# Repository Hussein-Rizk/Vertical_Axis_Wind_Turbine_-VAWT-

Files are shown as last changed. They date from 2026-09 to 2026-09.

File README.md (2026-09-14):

# 🌬️ Vertical Axis Wind Turbine (VAWT) — Graduation Project I

**Year:** 2024  
**Program:** Mechatronics Engineering  
**University:** Mansoura University  
**Main Tools:** QBlade, SolidWorks, AirfoilTools  
**Project Type:** Graduation Project I  

This project investigates the **design, aerodynamic analysis, simulation, and prototyping of a Vertical Axis Wind Turbine (VAWT)**.

The work combines a theoretical comparison between **Horizontal Axis Wind Turbines (HAWTs)** and **Vertical Axis Wind Turbines (VAWTs)** with airfoil selection, QBlade simulation studies, CAD design, manufacturing preparation, and construction of a physical VAWT prototype.

The final prototype was developed after comparing several NACA airfoils and evaluating turbine performance using **QBlade**.

---

## 📸 VAWT Prototype

<p align="center">
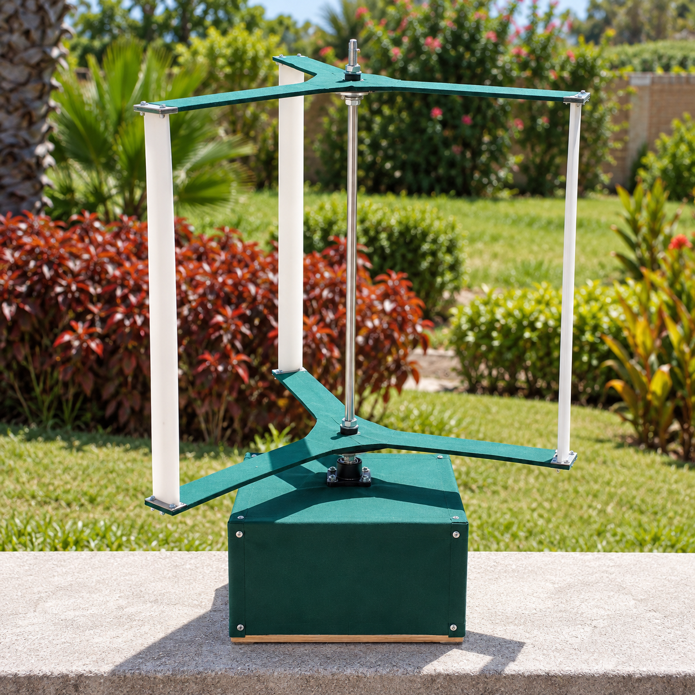
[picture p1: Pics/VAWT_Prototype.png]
  
</p>

The image above shows the fabricated **Vertical Axis Wind Turbine prototype** developed during the project.

---

## 🎯 Project Objectives

The project focuses on:

- studying the differences between **HAWT** and **VAWT** systems
- investigating aerodynamic parameters affecting wind-turbine performance
- comparing different **NACA airfoils**
- studying lift, drag, glide ratio, Reynolds number, tip-speed ratio, and power coefficient
- creating HAWT and VAWT case studies in **QBlade**
- selecting a suitable airfoil for the final VAWT prototype
- designing prototype components in **SolidWorks**
- preparing **DXF files** for manufacturing / laser cutting
- constructing and testing a physical VAWT prototype

---

## 🌀 HAWT Study

The HAWT case study compares four NACA airfoils:

- **NACA 1408**
- **NACA 2412**
- **NACA 6409**
- **NACA 6412**

For each airfoil, the project studies parameters such as:

- blade chord distribution
- twist angle
- Reynolds number
- tip-speed ratio
- lift coefficient
- angle of attack

The calculated blade geometry was then implemented and evaluated in **QBlade**.

### HAWT Study Files

```text
HAWT/
├── NACA 1408 HAWT V1.1.qpr
├── NACA 1408 HAWT V1.1.xlsx
├── NACA 2412 HAWT V1.1.qpr
├── NACA 2412 HAWT V1.1.xlsx
├── NACA 6409 HAWT V1.1.qpr
├── NACA 6409 HAWT V1.1.xlsx
├── NACA 6412 HAWT V1.1.qpr
└── NACA 6412 HAWT V1.1.xlsx
```

---

## 🏙️ VAWT Study

The main VAWT airfoil comparison documented in the graduation project focuses on:

- **NACA 0012**
- **NACA 0015**
- **NACA 0018**
- **NACA 0020**

The airfoils were compared using aerodynamic characteristics including:

- lift coefficient
- drag coefficient
- glide ratio
- power coefficient
- angle of attack behavior

Based on the simulation results, **NACA 0018** was selected as the most suitable airfoil for the chosen VAWT geometry.

Additional QBlade trials and airfoil studies are also included in the repository.

---

## ⚙️ Final VAWT Design

The final prototype parameters documented in the project are:

| Parameter | Value |
|---|---:|
| Solidity | 0.8 |
| Reynolds Number | 64,000 |
| Tip-Speed Ratio | 4 |
| Swept Area | 0.3 m² |
| Number of Blades | 3 |
| Average Wind Velocity | 10 m/s |
| Aspect Ratio | 1 |
| Power Coefficient | 0.485 |
| Estimated Power | 40 W |

### Prototype Geometry

| Height | Chord | Radius | Circ. Angle |
|---:|---:|---:|---:|
| 0 m | 0.3 m | 0.3 m | 0° |
| 0.5 m | 0.3 m | 0.3 m | 0° |

The final turbine uses a **three-blade vertical-axis configuration** built around a central vertical shaft.

---

## 🧪 QBlade

**QBlade** was used as the main aerodynamic simulation tool for the project.

It was used for:

- airfoil analysis
- lift and drag evaluation
- blade geometry definition
- HAWT and VAWT modeling
- power-coefficient analysis
- tip-speed-ratio studies
- aerodynamic turbine simulation
- wake visualization

QBlade project files are stored in the `HAWT/` and `VAWT/` folders.

---

## ✈️ Airfoil Data

Airfoil geometry and aerodynamic data were researched using **AirfoilTools**.

🔗 **AirfoilTools:** http://www.airfoiltools.com/

The repository also includes saved airfoil-reference material used during the project, including XFOIL polar data for selected profiles.

---

## 🧱 SolidWorks Design

The prototype components and trial parts were modeled in **SolidWorks**.

The CAD files include parts used for:

- turbine supports
- hub / rotor components
- blade mounting
- structural elements
- manufacturing trials

These files are stored in:

```text
Solidworks/
```

The SolidWorks geometry was also used as the basis for producing manufacturing-ready DXF files.

---

## 🏭 DXF Manufacturing Files

The `DXF/` folder contains 2D manufacturing profiles exported from the CAD designs.

```text
DXF/
├── c base.DXF
├── ci.DXF
├── hmm.DXF
├── hub new.DXF
├── Part1.DXF
└── turbine_6mm_wood.DXF
```

These files were prepared for fabrication processes such as **laser cutting / profile cutting**.

---

## 📚 Project Documentation

Two main documents explain the project:

### Graduation Project Book

[`Graduation_Project_1_Book.docx`](./Graduation_Project_1_Book.docx)

The book contains:

- project description
- aerodynamic theory
- wind-turbine design parameters
- airfoil-selection criteria
- HAWT case studies
- VAWT case studies
- QBlade analysis
- prototype design
- SolidWorks design
- prototype construction
- cost analysis

### HAWT vs. VAWT Presentation

[`HAWTs_vs._VAWTs_Scientific_Analysis.pptx`](./HAWTs_vs._VAWTs_Scientific_Analysis.pptx)

The presentation summarizes:

- HAWT vs. VAWT differences
- axis of rotation
- wind-direction requirements
- efficiency
- starting wind speed
- design complexity
- materials
- operating principles
- QBlade capabilities

### Prototype Image

<p align="center">
  
</p>

---

## 🧠 What This Project Demonstrates

- wind-turbine aerodynamic analysis
- HAWT vs. VAWT comparison
- airfoil selection
- NACA airfoil evaluation
- QBlade simulation
- lift / drag analysis
- power-coefficient analysis
- tip-speed-ratio analysis
- blade geometry optimization
- SolidWorks CAD modeling
- DXF manufacturing preparation
- prototype development
- engineering documentation

---

## 📌 Project Information

**Project:** Vertical Axis Wind Turbine  
**Type:** Graduation Project I  
**Year:** 2024  
**Program:** Mechatronics Engineering  
**University:** Mansoura University  

**Supervisors:**

- Asst. Prof. Yahia M. Fouda
- Eng. Ahmed Elwan

> Graduation project combining aerodynamic analysis, QBlade simulation, CAD design, manufacturing preparation, and physical prototyping of a small-scale Vertical Axis Wind Turbine.

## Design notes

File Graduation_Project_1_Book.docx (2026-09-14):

MANSOURA UNIVERSITY

FACULTY OF ENGINEERING

MECHATRONICS ENGINEERING PROGRAM

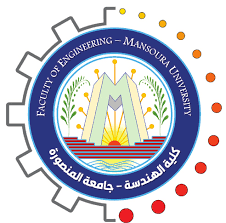
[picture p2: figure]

# Vertical Axis Wind Turbine

Project members ID number

Ahmed Mohamed Abo Elenein 803089392

Ahmed Mohamed Hamza Shokrof 803089507

Aser Amr El-Sayed Gabr 803089272

Eyad Medhat Mohamed Abdeljawad 803089397

Faris El-Sayed Nabeeh Elasaly 806096665

Hussain Ahmed Ibrahim Abdelaziz 803084842

Kareem Abdelaziz Ibrahim Abdallah 803089481

Mohamed Ahmed Fouad Ahmed Mansy 805771560

Mohamed Elsayed Mohamed Elfagal 803091617

Supervisors:

Asst. Prof. Yahia M. Fouda

Eng. Ahmed Elwan

Academic Year: Spring 2023-2024

# Acknowledgement

We would like to express our deepest gratitude to Dr. Yahia Fouda for his continues guidance and mentorship throughout the project, we also thank Eng. Ahmed Elwan for being the consultant and advisor we needed. The recommendations we got were of upmost value and dramatically improved the quality of our project. We cannot forget our friends and colleagues who provided us with their prior experiences, we thank every single one of you all. Last but not least, we are obligated to mention our families, their constant encouragement and support during our study years in this faculty will always be the driving force for every success we make, for that, we are so thankful.

# Abstract

This project investigates the design, implementation, and performance analysis of a Vertical Axis Wind Turbine (VAWT). Unlike traditional Horizontal Axis Wind Turbines (HAWTs), VAWTs feature a vertically oriented rotor shaft and blades, enabling them to capture wind from any direction, which makes them particularly suitable for urban settings and turbulent wind conditions. The study includes a thorough review of existing VAWT designs, highlighting their advantages and challenges. A prototype VAWT is developed, incorporating advanced materials and aerodynamic optimizations to enhance efficiency and durability. The performance of the turbine is analyzed using QBlade simulation software, supplemented by real-world testing. The results demonstrate that VAWTs can achieve competitive efficiency levels, with additional benefits such as lower noise, ease of maintenance, and better adaptation to varying wind patterns. This project contributes to the expanding research on wind energy technologies, showcasing the potential of VAWTs to complement traditional energy systems and support sustainable urban energy solutions.

# Table of contents

# List of Figure

# List of Tables

# List of Abbreviations

Symbol | Definition
AOA | Angle of attack
CFD | Computational fluid dynamics
GR | Glide ratio
HAWT | Horizontal axis wind turbine
VAWT | Vertical axis wind turbine
A | Swept area
N | Number of blades
NACA | National advisory committee for aeronautics
Re | Reynolds number
Rpm | Revolution per minutes
λ | Tip speed ratio
C | Chord of airfoil
C_D | Drag coefficient
C_L | Lift coefficient
C_m | Pitching moment coefficient
C_p | Power coefficient
D | Drag force
F | Force
F_(max) | Maximum thurst force
F_T | Thurst force
L | Lift force
M | Moment
P_w | Power
P | Pressure
U | Wind velocity
T_s | Starting torque
V_0 | Upstream speed
V_(∞) | Mean wind speed over a suitable time period
A | Angle of attack
L | Tip speed ratio
µ | Fluid viscosity
R | Fluid density

# Chapter 1: Project Description

Figure ‎1-1 CE Certification Innovative H-Type Vertical Axis Wind Turbine – Clean Energy Solution for Residential and Commercial Use Manufacturer and Product | Shenghuang

## 1. introduction

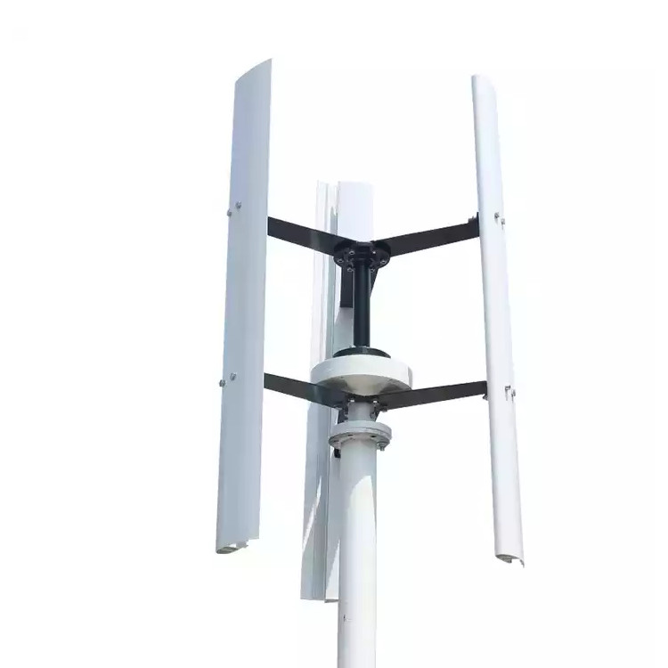
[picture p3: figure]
CE Certification Innovative H-Type Vertical Axis Wind Turbine – Clean Energy Solution for Residential and Commercial Use Manufacturer and Product | Shenghuang

As the world confronts the escalating challenges of climate change and the depletion of fossil fuels, the quest for sustainable and renewable energy sources has never been more critical. Among the myriad of solutions being explored, wind energy stands out as a particularly promising option due to its abundance and potential for reducing carbon emissions. Within this sphere, vertical wind turbines (VAWTs) are garnering increasing attention as an innovative alternative to the more traditional horizontal-axis wind turbines (HAWTs).

This project book delves into the intricacies of vertical wind turbines, examining their design, functionality, and potential impact on the renewable energy landscape. Unlike their horizontal counterparts, VAWTs feature blades that rotate around a vertical axis, a design that imparts several unique advantages and poses distinct challenges. Throughout this book, we will explore these aspects in detail, offering a comprehensive overview of the benefits and drawbacks associated with VAWTs.

## 2. wind turbines effect on climate

Wind turbines play a crucial role in combating climate change by providing a clean, renewable source of energy that significantly reduces greenhouse gas emissions. Unlike fossil fuels, which release large amounts of carbon dioxide and other harmful pollutants into the atmosphere when burned, wind energy harnesses the natural power of the wind to generate electricity without producing any direct emissions. This transition from fossil fuels to wind energy is essential in mitigating the effects of global warming, as it helps to decrease our carbon footprint and reliance on non-renewable energy sources. Additionally, wind turbines contribute to energy diversification and security, reducing the vulnerability of energy systems to geopolitical tensions and price fluctuations associated with fossil fuels. By enabling a sustainable and environmentally friendly energy infrastructure, wind turbines are a vital component in the global strategy to address and reverse the impacts of climate change.

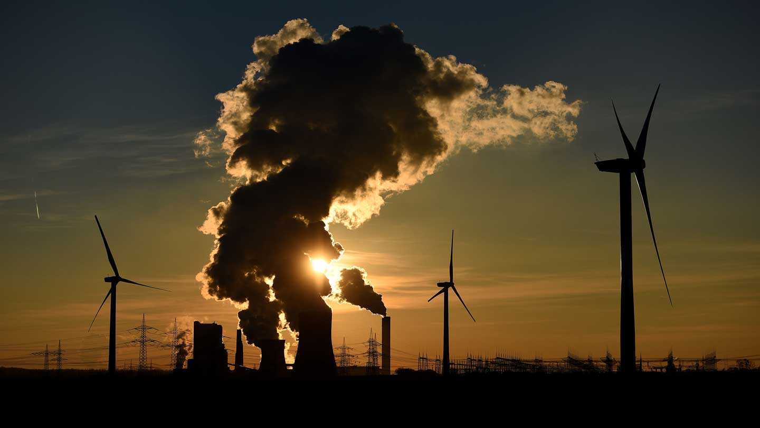
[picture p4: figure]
Wind turbines could help capture carbon dioxide while providing power

Figure ‎1-2: Carbon emissions vs wind turbines.

## 3. project scope

## 3.1 Objective

The objective of this project is to design, develop, and evaluate a Vertical Axis Wind Turbine (VAWT) that is efficient, cost-effective, and suitable for use in both urban and rural settings. The project aims to address the unique challenges associated with VAWTs while maximizing their advantages to contribute to sustainable energy solutions.

## 3.2 Key Deliverables

Design Specifications: Detailed blueprints and specifications for the VAWT, including blade design, materials, and structural components.

Prototype Development: Construction of a working prototype based on the finalized design specifications.

Performance Analysis: Comprehensive testing of the prototype under various wind conditions to assess efficiency, durability, and energy output.

Cost-Benefit Analysis: Economic analysis comparing the cost of production, installation, and maintenance of the VAWT with traditional Horizontal Axis Wind Turbines (HAWTs) and other renewable energy sources.

Environmental Impact Assessment: Evaluation of the environmental benefits and potential impacts of deploying VAWTs on a larger scale.

Implementation Plan: A strategic plan for scaling up production and deployment, including site selection criteria, installation guidelines, and maintenance schedules.

## 3.3 Project Phases:

### 3.3.1 Research and Planning:

  - Conduct literature review and feasibility studies.
  - Define project goals, scope, and deliverables.
  - Develop initial design concepts and select the most promising approach.

### 3.3.2 Design and Development:

  - Create detailed engineering designs and simulations.
  - Select appropriate materials and manufacturing techniques.
  - Develop and assemble the prototype.

### 3.3.3 Testing and Evaluation:

  - Perform laboratory and field tests to measure performance metrics such as efficiency, durability, and power output.
  - Analyze data to refine design and improve performance.

### 3.3.4 Economic and Environmental Analysis:

  - Conduct a cost-benefit analysis to determine economic viability.
  - Assess environmental impacts and benefits.

### 3.3.5 Documentation and Reporting:

  - Compile a comprehensive project report detailing the design process, testing results, and analysis.
  - Prepare user manuals and maintenance guidelines.

### 3.3.6 Deployment Strategy:

  - Develop a detailed plan for scaling up production and installation.
  - Identify potential sites and market opportunities.

## 3 suitable locations

Site Selection for wind farms represents a challenging contradiction for spatial analysts. The ideal location should be somewhere remote but not too remote. Not too close to residents, but with sufficient power and transport infrastructure able to support construction and operations. A site should experience high wind speeds (often found in upland areas) but should not be ecologically sensitive to avoid the energy development causing negative environmental impacts.

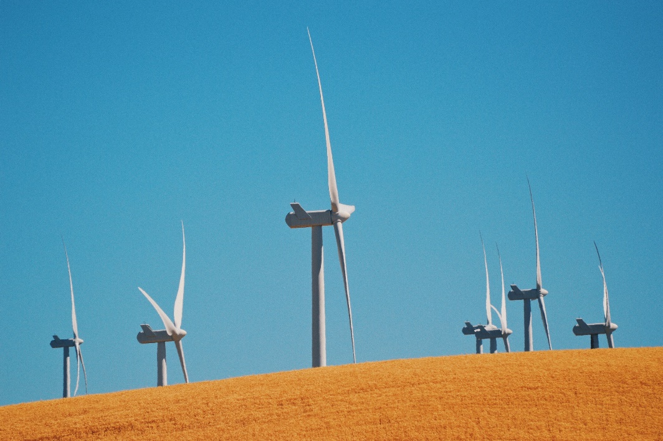
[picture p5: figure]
A photograph of 7 wind turbines in a field

Figure ‎1-3: Wind turbines farm site

## 4.1 Suitable sites in egypt for wind energy

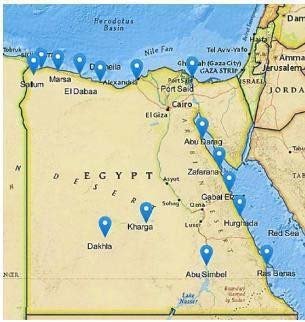
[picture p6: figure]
The locations of the most promising sites along Egypt's shores for wind energy

Figure ‎1-4: Best location sites for wind energy in Egypt

## 4 Advantages and disadvantages

### 4.1 Advantages

One of the primary advantages of VAWTs is their ability to operate in a variety of wind conditions, including turbulent and low-speed winds, which makes them suitable for urban and residential areas. Their omnidirectional design allows them to capture wind from any direction without requiring a yaw mechanism to align the rotor. This simplicity in design can lead to lower maintenance costs and increased durability. Additionally, VAWTs generally have a smaller physical footprint and can be installed closer to the ground, reducing installation complexity and visual impact.

### 4.2 Disadvantages

However, VAWTs are not without their limitations. They often suffer from lower efficiency compared to HAWTs, primarily due to the less aerodynamic design of their blades and the additional drag forces encountered during operation. This can result in lower energy output, which may limit their viability in large-scale energy projects. Furthermore, the structural stresses and mechanical wear unique to the vertical design can pose engineering challenges, potentially affecting longevity and reliability.

This project book aims to provide a balanced examination of vertical wind turbines, assessing both their potential to contribute to sustainable energy solutions and the technical hurdles that must be overcome. By exploring real-world case studies, innovative design improvements, and future prospects, we seek to offer a thorough understanding of where VAWTs fit into the broader context of renewable energy technologies.

As we embark on this exploration, it is crucial to maintain a forward-looking perspective, recognizing that the advancement of renewable energy technologies like vertical wind turbines will be pivotal in shaping a sustainable and resilient future.

# Chapter 2: Aerodynamic Analysis

## 2.1 Introduction:

In this section, the rotor design parameters are described as well as the model used to calculate its aerodynamic performance, so to understand the behavior of the wind turbine blades, there should be a good understanding of the wind characteristics and the aerodynamics of air foil.

## 2.2 Wind turbine design parameters:

The wind turbine parameters considered in the design process are:

• Swept area

• Power and power coefficient

• Tip speed ratio

• Blade chord

• Number of blades

• Solidity

• Initial angle of attack

### 2.2.1 Swept area:

The swept area is the section of air that encloses the turbine in its movement, the shape of the swept area depends on the rotor configuration, this way the swept area of an HAWT is circular shaped while for a straight-bladed vertical axis wind turbine the swept area has a rectangular shape and is calculated:

S= 2RL

where S is the swept area [m²], R is the rotor radius [m], and L is the blade length [m].

The swept area limits the volume of air passing by the turbine. The rotor converts the energy contained in the wind in rotational movement so the larger the area, the larger the power output in the same wind conditions.

### 2.2.2 Power and power coefficient:

The power available from wind for a vertical axis wind turbine can be found from

the following formula: P_w =1/2ρsU^3

where U is the velocity of the wind [m/s] and ρ is the air density [kg/m³], the reference density used is standard sea level value (1.225 kg/m³ at 15ºC). Note that available power is dependent on the cube of the airspeed.

The power the turbine takes from wind is calculated using the power coefficient:

C_p =(Captured mechanical power by blades)/(Available power in wind (P_w ))

C_p value represents the part of the total available power that is taken from wind, which can be understood as its efficiency.

There is a theoretical limit in the efficiency of a wind turbine determined by the deceleration the wind suffers when going across the turbine.

For HAWT, the limit is 19/27 (59.3%) and is called Lanchester-Betz limit. Often this limit is also applied to vertical axis wind turbines (VAWT). However, a literature review reveals that early analytical and recent numerical approaches predicted values for the maximum power output of VAWTs close to or even higher than the Betz limit. For VAWT, the limit is 16/25 (64%).

This power coefficient only considers the mechanical energy converted directly from wind energy, it does not consider the mechanical-into-electrical energy conversion, which involves other parameters like the generator efficiency.

### 2.2.3 Tip Speed Ratio λ :

The power coefficient is strongly dependent on tip speed ratio, defined as the ratio between the tangential speed at blade tip and the actual wind speed:

λ =(RΩ)/U

where Ω is the angular speed [rad/s], R the rotor radius [m] and U the ambient wind speed [m/s]. Each rotor design has an optimal tip speed ratio at which the maximum power extraction is achieved. This optimal λ presents a variation depending on ambient wind speed.

### 2.2.4 Blade chord:

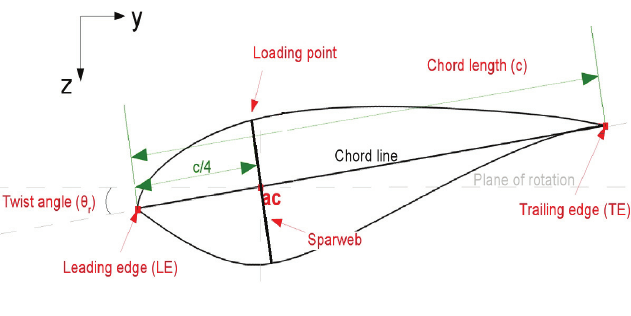
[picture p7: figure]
A diagram of a chord line and airfoil geometry

The chord is the length between the leading edge and trailing edge of the blade profile.
The blade thickness and shape are determined by the air foil used, in this case it will be a NACA air foil, where the blade curvature and maximum thickness are defined as percentage of the chord.

Figure ‎2-1 blade chord

### 2.2.5 Number of blades:

The number of blades has a direct effect in the smoothness of rotor operation as they can compensate cycled aerodynamic loads. For easiness of building, four and three blades have been contemplated.

### 2.2.6 Solidity:

The solidity σ is defined as the ratio between the total blade area and the projected turbine area.
It is an important non-dimensional parameter which affects self-starting capabilities and for VAWTs is calculated with:

σ=(Nc)/R

where N is the number of blades, c is the blade chord, R is the radius; it is considered that each blade sweeps the area twice.

This formula is not applicable for HAWT as they have different shape of swept area.

Solidity determines when the assumptions of the momentum models are applicable, and only when using σ ≥ 0.4 a self-starting turbine is achieved.

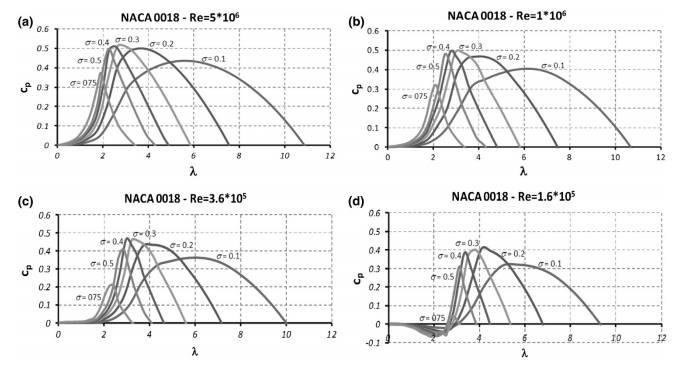
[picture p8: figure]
Solidity effect on power coefficient

Figure ‎2-2 Solidity effect on power coefficient

### 2.2.7 Initial angle of attack α

The initial angle of attack is the angle the blade has regarding its trajectory, considering negative the angle that locates the blade’s leading edge inside the circumference described by the blade path.

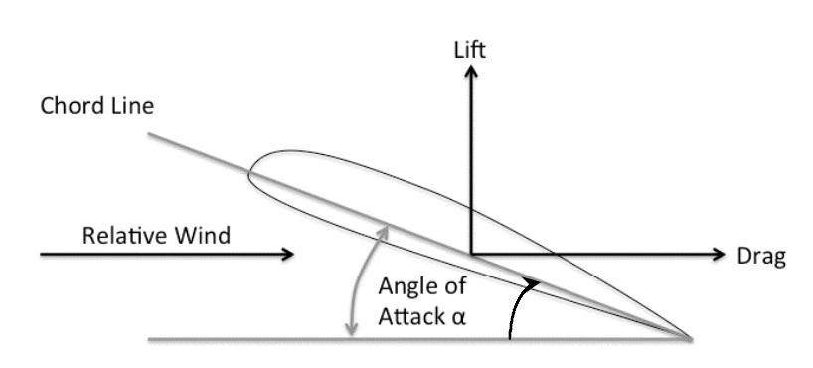
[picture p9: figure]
angle of attack

Figure ‎2-3 angle of attack

### 2.2.8 Coefficient of moment C_m

The moment coefficient is the percentage of torque received by the wind turbine through the swept area of the turbine blades.

Equation depicts how to calculate the coefficient of moment:

C_m =(T_B)/(0.5 ρ||U||2SR)

Where U is the wind velocity [m/s], T_B is the shaft torque [N.m].

2.3 Physics of the Vertical Axis Wind Turbine:

The wind exerts a force on the blade. This force can be split up into a drag force F_L along the effective wind vector v_(re_l) and a lift force F_L perpendicular to it.

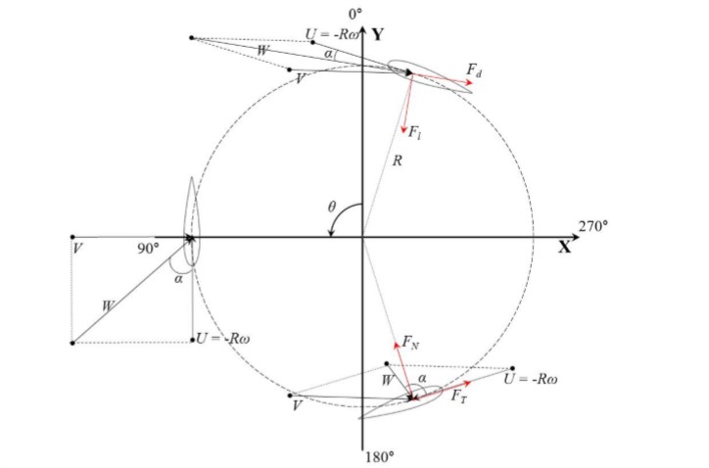
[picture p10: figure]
force and velocities acting on vertical wind turbine for various azimuth angles.

Figure ‎2-4 force and velocities acting on vertical wind turbine for various azimuth angles.

Figure 2-4 shows a picture of the basic parameters of the small wind turbine system, and the velocity profile V(Z) is shown in the next Equation:

V(Z)=v_(rel) (z/(z_(rel)))^a

The wind shear power index a can be varied according to the surface roughness.

Figure 2.4 presents the tip velocity vector and the lift, and the drag vectors generated by the rotation of the turbine blade. The angle of attack changes with the blade tip velocity vector and the influx wind velocity vector. The vector sum W of the tip velocity vector and incoming wind velocity vector V is calculated by the next equation. The maximum value occurs at θ = 0◦, and the minimum value occurs at θ = 180◦.

W=√(v^2 [(λ-sinθ^2 )^2 +cosθ^2 ])=v√(1+2λcosθ+λ^2)

The angle of attack α is the angle between the vector sum and the direction of the chord length. As the vector sum changes, the angle of attack has a positive value in the upstream region of the rotor and a negative value in the downstream region. The angle of attack can be expressed as in follows:

α=tan^(-1) (sinθ/(cosθ+λ))

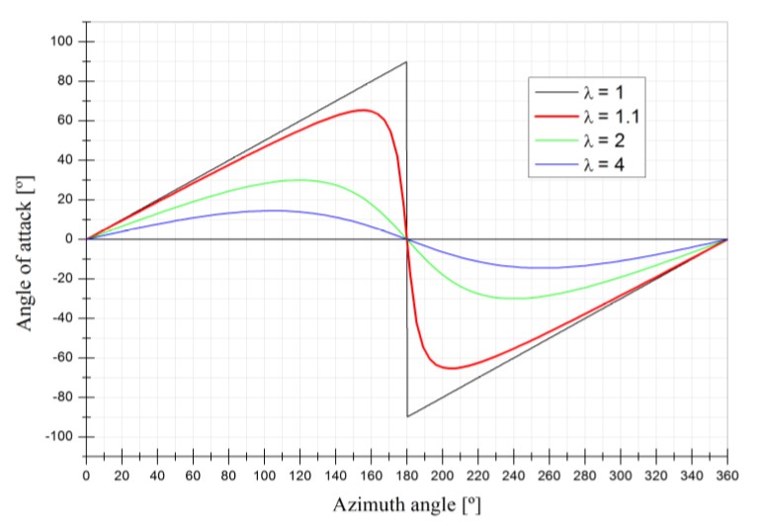
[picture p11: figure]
Angle of attack variation in a blade revolution for different tip speed ratio.

As shown in the equation the dominant variable that affects the angle of attack is the tip speed ratio. Figure 2-4 shows the angle of attack as the blade rotates according to the tip speed ratio. The larger the tip speed ratio, the smaller the range of the angle of attack the airfoil receives during rotation. The larger the blade tip velocity vector is, the larger the tip speed ratio is. This occurs because the vector sum direction approaches the direction of the blade’s forward velocity vector, and the angle of attack becomes smaller. The range of the angle of attack of the airfoil is about ±66.5◦ in one rotation of the rotor.

Figure ‎2-5 Angle of attack variation in a blade revolution for different tip speed ratio.

The lift force F_L is orthogonal to the vector v_(rel) and the drag force F_D is parallel to v_(rel) . The lift and drag forces can be estimated as:

F_L = 0.5 ρ A_(blade) v_(rⅇL)^2 CL

F_D = 0.5 ρ A_(blade) v_(rⅇL)^2 CD

Since these coefficients are proportional to their respective forces, the following also holds for the coefficients of the tangential force and normal force:

C_t = C_L sin(α) - C_D cos(α)

C_n = C_L cos(α) + C_D sin(α)

ρ : is the flow density.

A_(blade) is the blade area.

C_L and C_D : are the lift and drag coefficients, which mainly are the functions of the angle of attack, aspect ratio, the Reynolds number and the air foil profile.

# Chapter 3: Design Approach

## 3.1 Introduction

As mentioned earlier, there are main two types of VAWTs.

In this chapter, we will discuss two designs of them and make a small-scale 3D model for each one; in order to achieve an efficient and reliable product for budgeted cost.

To select the proper design to be a final product, we have got a primary data about the two types to make a comparison between them.

The following steps are taken to select the proper design.

## 3.2 studying airfoil characteristics

One of the most important factors affecting the wind turbine is the air foil profile selection. Which should have the optimal ratio of lift to drag force glide ratio C_l /C_d .

### 3.2.1 The aerodynamic criteria affecting the airfoil selection

1. The glide ratio C_l /C_d
- The glide ratio C_l /C_d shows the total efficiency of any air foil and inevitably, it is ideal to be higher over a large range of angle of attack α to increase the aerodynamic performance
2. Maximum lift coefficient C_l
- This would improve the starting torque and more positive torque will be produced.
3. Wide drag bucket
- The airfoils have the lowest drag over a small spectrum of angle of attack α which is called the drag bucket, and the form of the airfoil defines the shape and location of the drag bucket.
4. Low drag coefficient C_d
- The required airfoil should have the least amount of drag, particularly the zero-lift-drag coefficient C_(d0) which is a reflection of parasitic drag “realize how pure or smooth the aerodynamics of the VAWTs is”.
5. High stall angle at small Reynolds number
- Should be as large as possible in the low Reynolds number operation.

### 3.2.2 Desirable geometric feature of an air foil

We should consider these features while selecting an air foil:

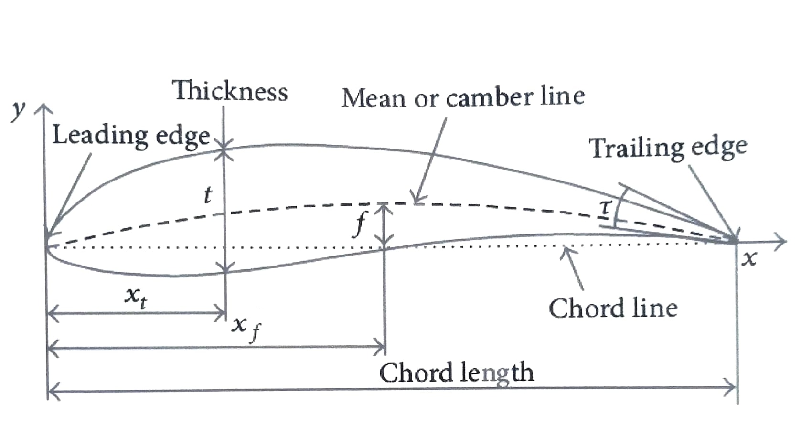
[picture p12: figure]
geometric feature of an air foil.

Figure ‎3-1 geometric feature of an air foil

1- Cambered airfoil
- Will generate a high tangential thrust over a boarder range of α , more energy per revolution, and therefore the VAWT would self-start using the cambered blade.
2- Large leading-edge radius
- The greater leading-edge radius would result in less susceptible to roughness, better VAWT energy harness when the blade gets dirty due to being prone to the elements of nature, and also increased airfoil lift-drag ratio at a wide range of α .
3- Sharp trailing edge
- Which greatly decrease the minimum drag coefficient. It should notice that the manufacturing of sharp trailing edges is always complicated and expensive.
4- Greater thickness
- Blades with thicker airfoils shapes have several advantages:
  a- Increasing in starting torque
  b- Increasing in width of the drag bucket
  c- Improvement of structural strength
  d- Improvement of the performance of VAWT

### 3.2.3 Selection of optimal airfoil

In addition to selection of air foil profile, there are parameters must be considered are following

1- Average wind speed
2- Air density
3- Reynolds number
4- Atmospheric pressure

In the next section of this chapter we are going to study the two different design studies, analysis, and comparison between them will be executed on Qblade software.

## 3.3 Qblade HAWT study

### 3.3.1 Q-blade model

The selection of airfoil and different design parameters to make an efficient design are shown in the next steps.

We chose three airfoils from the NACA to find which one has the highest lift-drag ratio at low Reynolds number, all of them satisfy the desired geometric features discussed before.

these airfoils are [NACA 1408, NACA 2412, NACA 6409, NACA 6412]

the λ is chosen that it makes the highest cord length to be 20% of the radius

λ= ΩR/U

λ_r = Ωr/U = λr/R

φ=tan^(-1) (2/(3λ_r))

c=(8pirsinφ)/(3BC_l λ_r)

R_e =(UL)/ν

Ω Where is the angular velocity, R is the radius of the blade, λ is the tip speed ratio, λ_r is the local tip speed ratio, φ is the twist angle, c is the chord length, B is the number of blades, and C_l is the lift cofftient

We apply the previous equations to obtain the chord length c and twist angle φ for each airfoil in excel to the next results:

Table ‎3-1 HAWT study for NACA 1408 airfoil

Tip Speed Ratio (TSR) | | | 9 | Wind Speed | | 5
NO. of Rotor Blades (B) | | | 3 | Kinematic Viscosity | | 1.48E-05
Blade length (R) | | | 1 | Lift coefficient (CL) | | 0.62
Angle of Attack (AOA) for MAX Glide Ratio | | | 4 | Air Foil | | NACA 1408
| Fraction of Rotor Radius r/R | Chord (C) | Angle of rel. wind (deg) ɸi | Twist Angle (deg) ɵT,i | Reynlods Number (Re) | Tip Speed Ratio Range
1 | 0.1 | 0.298 | 36.55 | 32.55 | 103485.98 | 0.9
2 | 0.2 | 0.174 | 20.33 | 16.33 | 60383.91 | 1.8
3 | 0.3 | 0.120 | 13.88 | 9.88 | 41676.64 | 2.7
4 | 0.4 | 0.091 | 10.50 | 6.50 | 31657.95 | 3.6
5 | 0.5 | 0.073 | 8.43 | 4.43 | 25478.88 | 4.5
6 | 0.6 | 0.061 | 7.04 | 3.04 | 21302.41 | 5.4
7 | 0.7 | 0.053 | 6.04 | 2.04 | 18295.68 | 6.3
8 | 0.8 | 0.046 | 5.29 | 1.29 | 16029.54 | 7.2
9 | 0.9 | 0.041 | 4.71 | 0.71 | 14261.21 | 8.1
10 | 1 | 0.037 | 4.24 | 0.24 | 12843.30 | 9

Table ‎3-2 HAWT study for NACA 2412 airfoil

Tip Speed Ratio (TSR) | | | 8 | Wind Speed | | 5
NO. of Rotor Blades (B) | | | 3 | Kinematic Viscosity | | 1.48E-05
Blade length (R) | | | 1 | Lift coefficient (CL) | | 0.83
Angle of Attack (AOA) for MAX Glide Ratio | | | 6 | Air Foil | | NACA 2412
| Fraction of Rotor Radius r/R | Chord (C) | Angle of rel. wind (deg) ɸi | Twist Angle (deg) ɵT,i | Reynlods Number (Re) | Tip Speed Ratio Range
1 | 0.1 | 0.269 | 39.83 | 33.83 | 93534.05 | 0.8
2 | 0.2 | 0.162 | 22.63 | 16.63 | 56194.17 | 1.6
3 | 0.3 | 0.113 | 15.53 | 9.53 | 39104.07 | 2.4
4 | 0.4 | 0.086 | 11.77 | 5.77 | 29798.71 | 3.2
5 | 0.5 | 0.069 | 9.47 | 3.47 | 24019.49 | 4
6 | 0.6 | 0.058 | 7.91 | 1.91 | 20099.41 | 4.8
7 | 0.7 | 0.050 | 6.79 | 0.79 | 17271.48 | 5.6
8 | 0.8 | 0.044 | 5.95 | -0.05 | 15137.35 | 6.4
9 | 0.9 | 0.039 | 5.29 | -0.71 | 13470.61 | 7.2
10 | 1 | 0.035 | 4.77 | -1.23 | 12133.35 | 8

Table ‎3-3 HAWT study for NACA 6409 airfoil

Tip Speed Ratio (TSR) | | | 6 | Wind Speed | | 5
NO. of Rotor Blades (B) | | | 3 | Kinematic Viscosity | | 1.48E-05
Blade length (R) | | | 1 | Lift coefficient (CL) | | 1.334
Angle of Attack (AOA) for MAX Glide Ratio | | | 8 | Air Foil | | NACA 6409
| Fraction of Rotor Radius r/R | Chord (C) | Angle of rel. wind (deg) ɸi | Twist Angle (deg) ɵT,i | Reynlods Number (Re) | Tip Speed Ratio Range
1 | 0.1 | 0.259 | 48.04 | 40.04 | 90092.02 | 0.6
2 | 0.2 | 0.169 | 29.07 | 21.07 | 58863.04 | 1.2
3 | 0.3 | 0.121 | 20.33 | 12.33 | 42096.73 | 1.8
4 | 0.4 | 0.093 | 15.53 | 7.53 | 32440.16 | 2.4
5 | 0.5 | 0.076 | 12.54 | 4.54 | 26293.36 | 3
6 | 0.6 | 0.063 | 10.50 | 2.50 | 22070.39 | 3.6
7 | 0.7 | 0.055 | 9.02 | 1.02 | 19001.23 | 4.2
8 | 0.8 | 0.048 | 7.91 | -0.09 | 16674.17 | 4.8
9 | 0.9 | 0.043 | 7.04 | -0.96 | 14851.01 | 5.4
10 | 1 | 0.039 | 6.34 | -1.66 | 13385.01 | 6

Table ‎3-4 HAWT study for NACA 6412 airfoil

Tip Speed Ratio (TSR) | | | 7 | Wind Speed | | 5
NO. of Rotor Blades (B) | | | 3 | Kinematic Viscosity | | 1.48E-05
Blade length (R) | | | 1 | Lift coefficient (CL) | | 1.299
Angle of Attack (AOA) for MAX Glide Ratio | | | 9 | Air Foil | | NACA 6412
| Fraction of Rotor Radius r/R | Chord (C) | Angle of rel. wind (deg) ɸi | Twist Angle (deg) ɵT,i | Reynlods Number (Re) | Tip Speed Ratio Range
1 | 0.1 | 0.212 | 43.62 | 34.62 | 73579.62 | 0.7
2 | 0.2 | 0.132 | 25.48 | 16.48 | 45869.80 | 1.4
3 | 0.3 | 0.093 | 17.62 | 8.62 | 32282.30 | 2.1
4 | 0.4 | 0.071 | 13.40 | 4.40 | 24711.70 | 2.8
5 | 0.5 | 0.057 | 10.79 | 1.79 | 19963.07 | 3.5
6 | 0.6 | 0.048 | 9.02 | 0.02 | 16725.60 | 4.2
7 | 0.7 | 0.041 | 7.75 | -1.25 | 14383.19 | 4.9
8 | 0.8 | 0.036 | 6.79 | -2.21 | 12612.19 | 5.6
9 | 0.9 | 0.032 | 6.04 | -2.96 | 11227.31 | 6.3
10 | 1 | 0.029 | 5.44 | -3.56 | 10115.22 | 7

Then we use the results from the tables in the Qblade software as shown for each study:

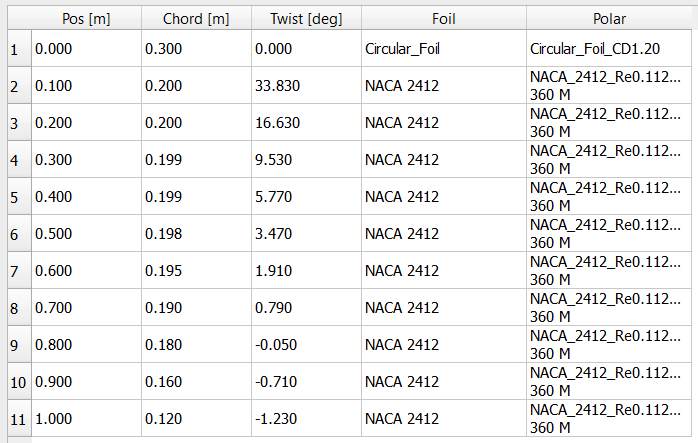
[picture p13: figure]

Figure ‎3-2 results in the Qblade software

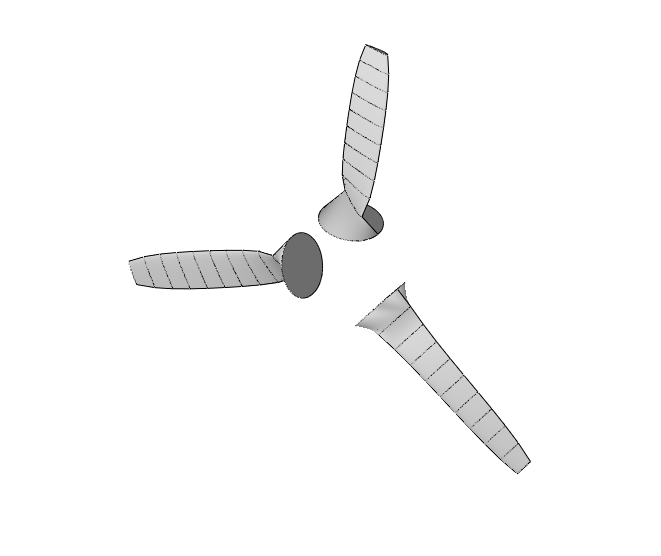
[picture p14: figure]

Figure ‎3-3 the output blades geometry

## 3.4 Qblade vAWT study and prototype

### 3.4.1 Q-blade model

The selection of airfoil and different design parameters to make an efficient design are shown in the next steps.

1- We chose three airfoils from the NACA series and compared to find which one has the highest lift-drag ratio and the power coefficient, all of them satisfy the desired geometric features discussed before.

these airfoils are [NACA 0012, NACA 0015, NACA 0018, NACA 0020]

2- The airfoils will be analyzed for conditions of: Re=6.4×10^4 , and average wind speed U= 5 m/s .

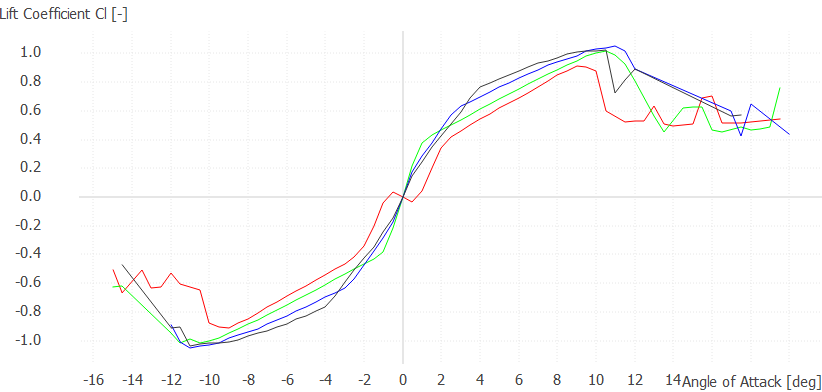
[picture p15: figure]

Figure ‎3-4 lift coefficient vs Angel of attack

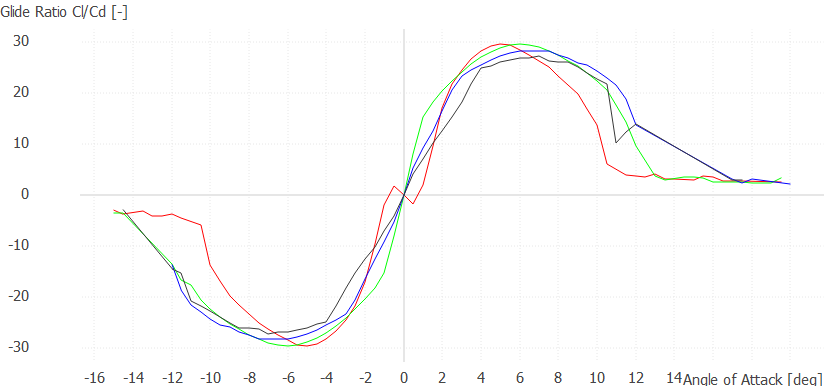
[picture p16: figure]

Figure ‎3-5 glide ratio vs Angel of attack

From the simulations we obtained that the airfoil NACA 0018 is the most suitable for the chosen geometry.

## 3.5 Design of the prototype

A prototype is built depending on simulation in Q-blade software as shown in Table 3.5 and 3.6

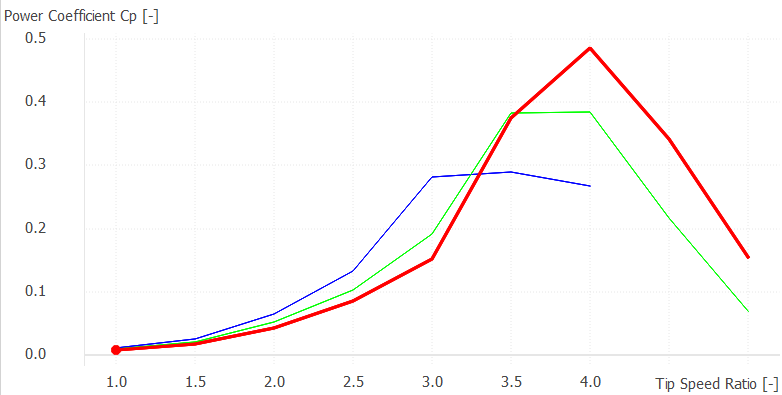
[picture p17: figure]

Figure ‎3-6 power coefficient C_p vs tip speed ratio λ

Table ‎3-5 simulation parameters

Solidity σ | 0.8
Reynold Number Re | 64000
Tip- speed ratio λ | 4
Swept area A | 0.3 m²
Number of blades B | 3
Average wind velocity U | 10 m/s
Aspect ratio | 1
Power coefficient C_p | 0.485
Power | 40 w

Table ‎3-6 prototype geometry

Height (m) | Chord (m) | Radius (m) | Circ Angle
0 | 0.3 | 0.3 | 0
0.5 | 0.3 | 0.3 | 0

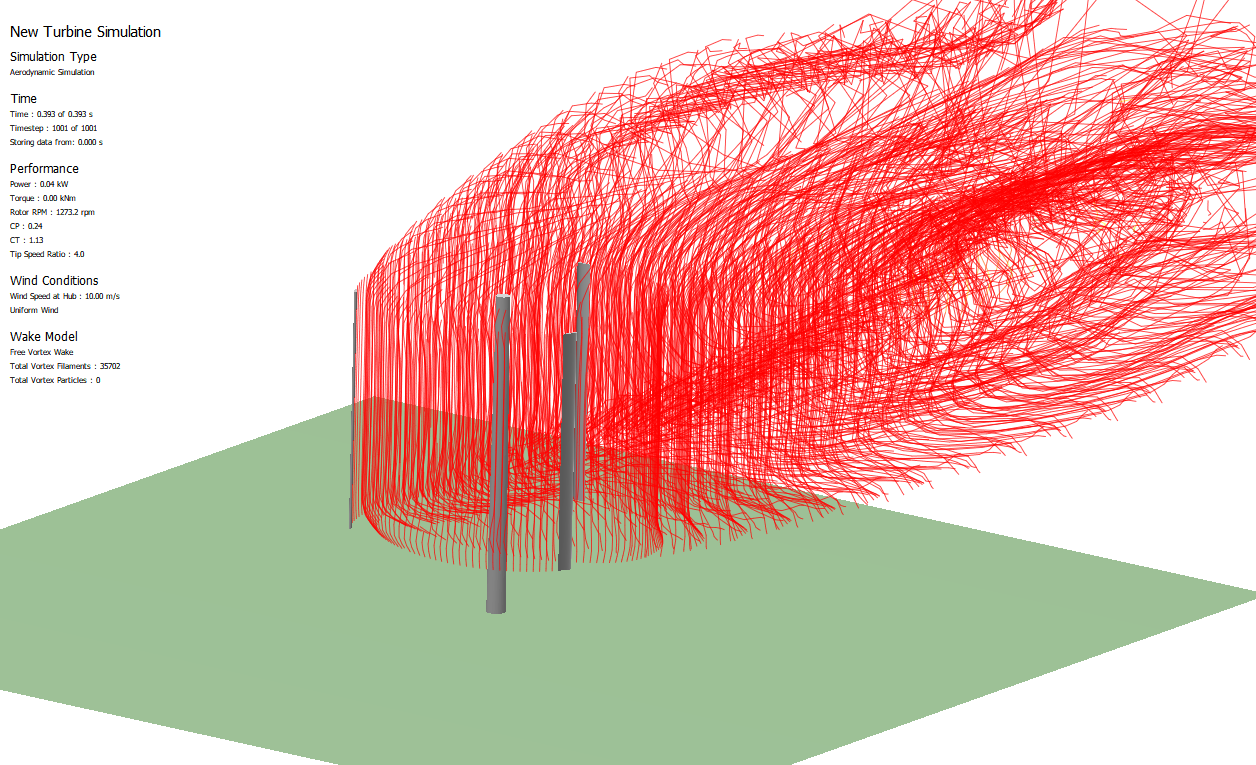
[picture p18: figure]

Figure ‎3-7 prototype simulation run

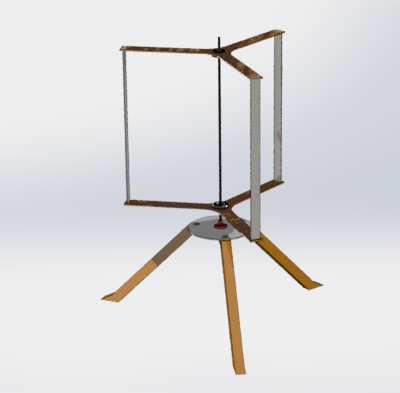
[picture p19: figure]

Figure ‎3-8 render of the prototype in SolidWorks

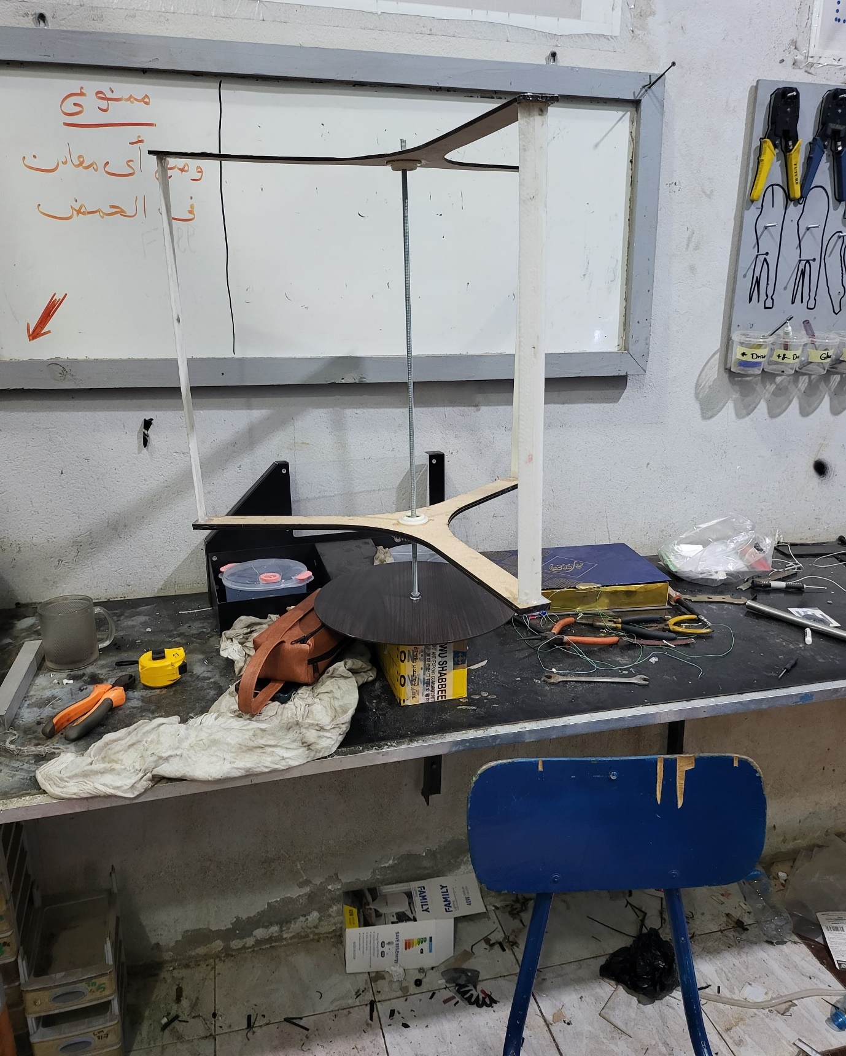
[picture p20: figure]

Figure ‎3-9 prototype shot 1

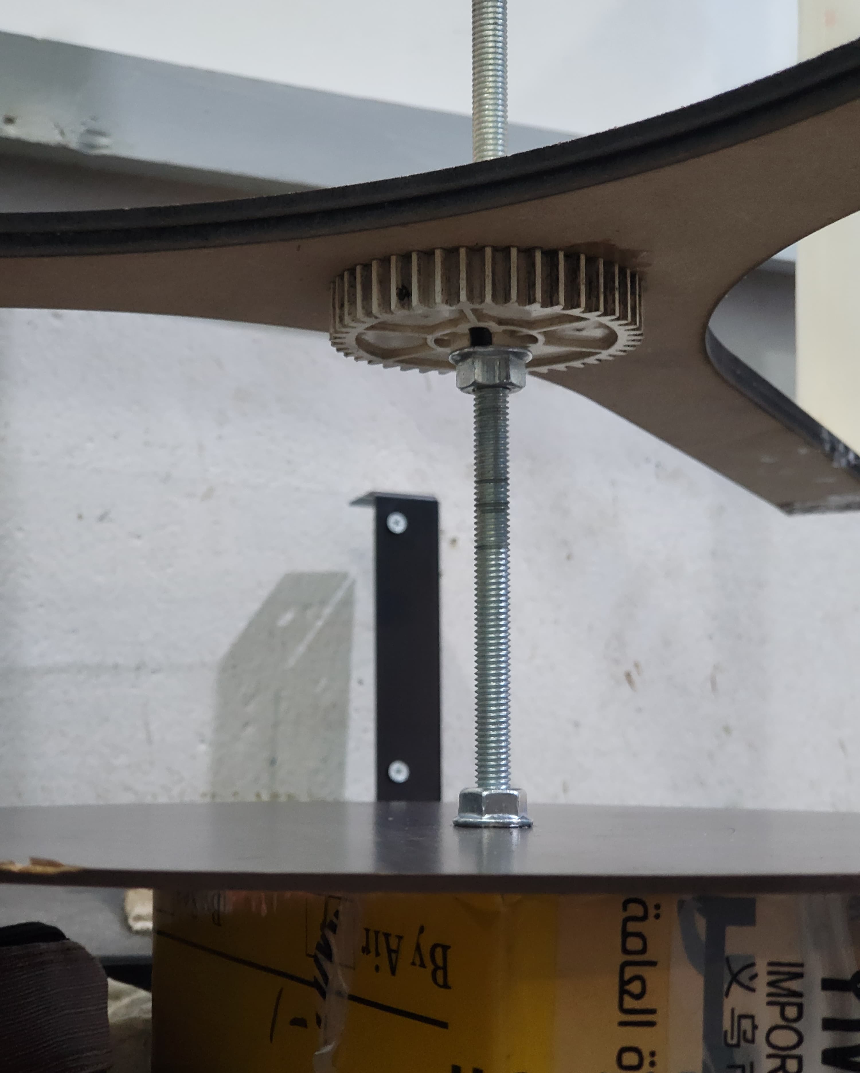
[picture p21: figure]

Figure ‎3-10 prototype base shot 2

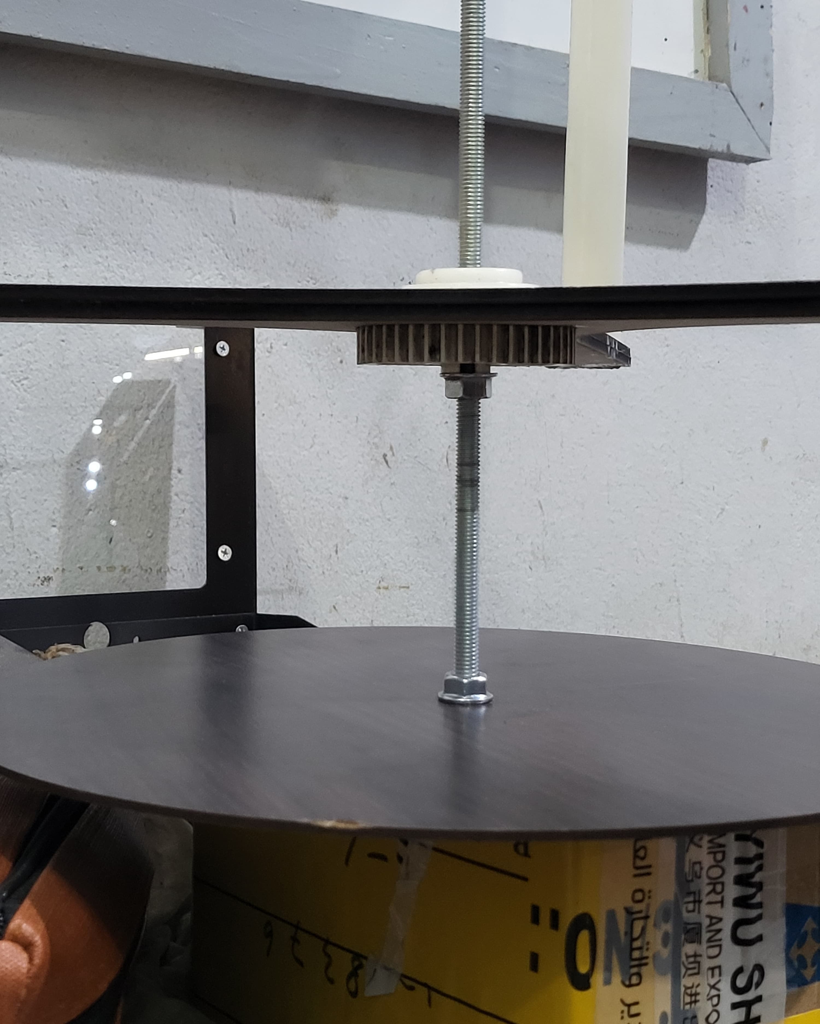
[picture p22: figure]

Figure ‎3-11 prototype base shot 3

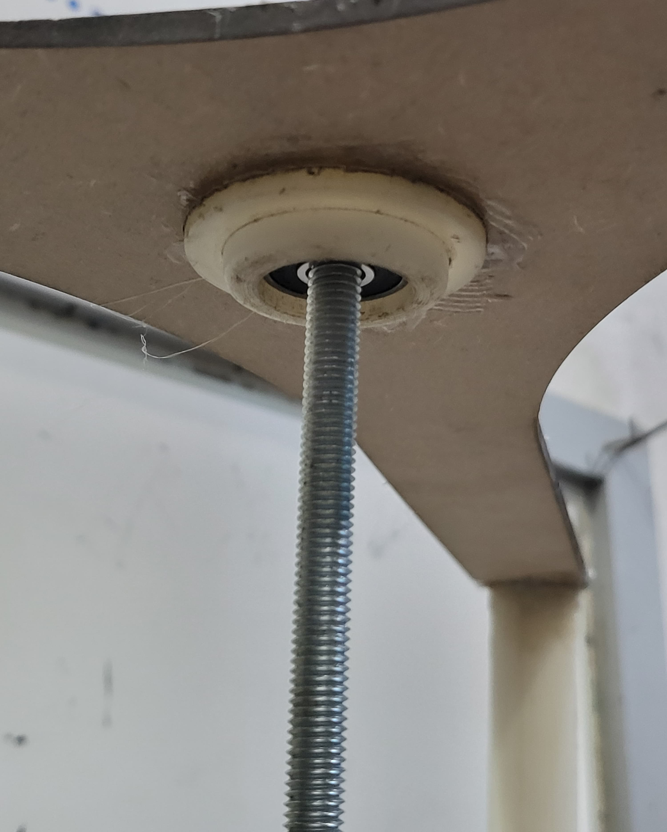
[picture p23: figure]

Figure ‎3-12 prototype fixation shot 4

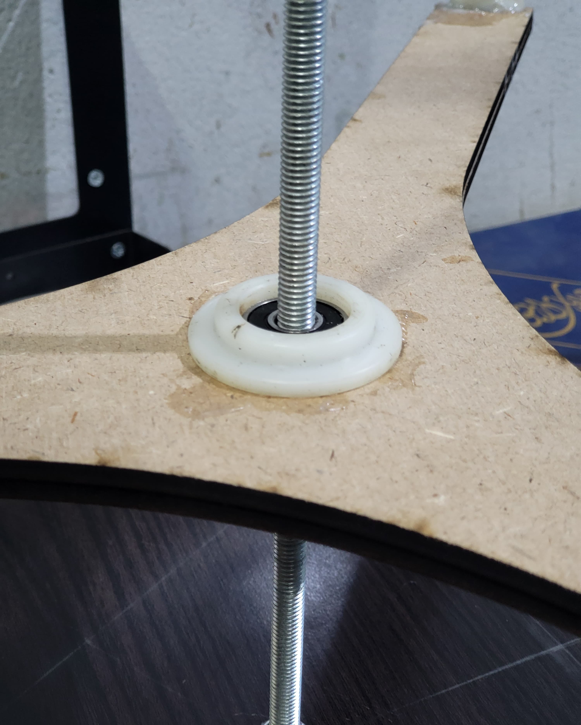
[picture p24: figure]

Figure ‎3-13 prototype shot 5

# Chapter 4: Economics of wind energy

## 4.1 Introduction

In this chapter, we will introduce the cost of electricity from the wind energy including the factors affect the cost and the methods of calculating it. In addition, we will summarize the total cost of our design and compare it with the commercial wind turbines used in bulk generation of electricity.

After that, we will mention simple calculations to predict the number of wind turbines of our design enough for a commercial place like small factory or apartment .

## 4.2 Wind energy cost analysis

The key parameters governing wind power economics are the:

  a. Investment costs (including those associated with project financing).
  b. Operation and maintenance costs (fixed and variable).
  c. Capacity factor (based on wind speeds and turbine availability factor).
  d. Economic lifetime.
  e. Cost of capital.

There are four phases of a typical wind farm time line “the major components of the cost of a wind farm “

1. Identify Site
2. Development
3. Construction
4. Operation and Maintenance

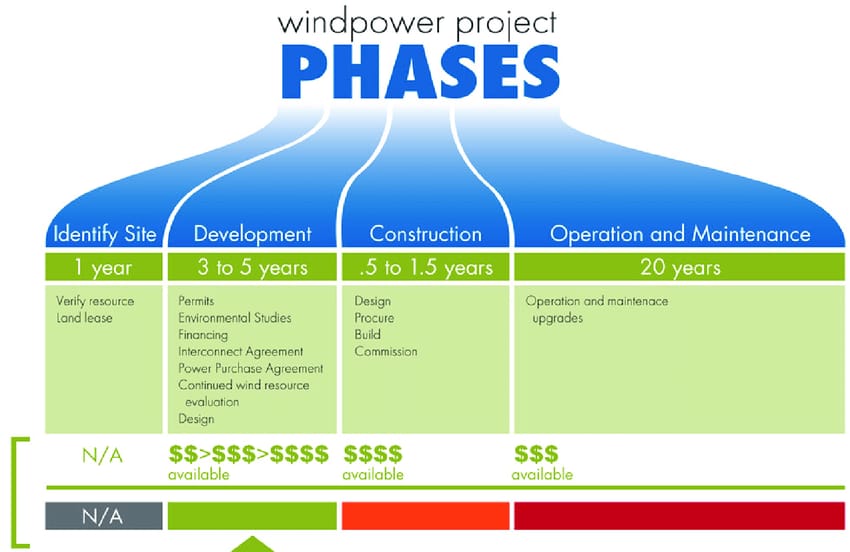
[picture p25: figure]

Figure ‎4-1 Time line for developing and operating a typical wind farm

From above , it is obvious that the wind turbines cost a lot . Therefore , the investment in wind energy is to be considered over a long period of time .

According to weather guard wind website in 2024:

1-The Breakdown of Initial Wind Turbine Costs

- $2.6 – $4 million per average-sized commercial wind turbine

Typical cost is $1.3 million per megawatt (MW) of electricity-producing capacity

- Most commercial wind turbines have a capacity of 2-3 MW, but offshore turbines can be as large as 16-18 MW (https://mfgtalkradio.com/worlds-powerful-wind-turbine-haliade-x-general-electric/) .
- Cost increases as turbine size increases, though there are benefits to using fewer, larger turbines – complexity and construction of the overall farm site is greatly reduced with fewer and larger turbines.

2- Wind Turbine Maintenance Costs

- 1-2 cents per kilowatt-hour produced, or $42,000 – $48,000 per year

This means that the cost of kW is nearly 2.1M LE. Per year

## 4.3 cost analysis of the PROJECT.

Table ‎4-1 The total cost for construction of our VAWT project

Part | Quantity | Cost | Total
Bearings | 2 | 100 | 200
Laser cut top | 2 | 350 | 700
3D Printed Blades | 330 | 330 | 990
Rod | 1 | 50 | 50
3d base | 1 | 100 | 100
Total | …… | …….. | 2040

# References

1) Brusca2014_Article_”DesignOfAVertical-axisWindTurbine”
2) " Global wind statistics " ( PDF ) . IRENA
3) Herbert J. Sutherland ,HJS Consulting “A Retrospective of VAWT Technology”
4) Travis J. Carrigan, Brian H. Dennis, Zhen X. Han, and Bo P.Wang “Aerodynamic Shape Optimization of a Vertical-AxisWind Turbine Using Differential Evolution”
5) Frederikus Wenehenubuna, Andy Saputraa, Sutanto “An experimental study on the performance of Savonius wind turbines related with the number of blades”
6) L. Battisti et al 2016 J. Phys “Analysis of Different Blade Architectures on small VAWT Performance”
7) Amlan Das “Modelling and Analysis of a Mini Vertical Axis Wind Turbine”
8) Junkun Ma “Drag Force on a Vertical Axis Wind Turbine with Airfoil Pitch Control”
9) Javier Castillo “SMALL-SCALE VERTICAL AXIS WIND TURBINE DESIGN”
10) M.A. Miller, S. Duvvuri, W. D. Kelly and M. Hultmark “Rotor solidity effects on the performance of vertical-axis wind turbines at high Reynolds numbers”

Faculty of Engineering, Mansoura University Mansoura, Egypt 2024

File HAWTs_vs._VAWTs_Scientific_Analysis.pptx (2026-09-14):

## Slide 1


HAWTs vs. VAWTs
Scientific Analysis

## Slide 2


Abstract

Wind turbines play a crucial role in harnessing renewable wind energy for electricity generation.
A comparative analysis of two prevalent wind turbine designs : Horizontal Axis Wind Turbines (HAWTs) and Vertical Axis Wind Turbines (VAWTs).
Delves into the key differences between these two types in terms of their axis of rotation, wind direction requirements, operational efficiency, starting wind speed, and overall complexity. Additionally, we will explore the common materials utilized in both HAWTs and VAWTs, followed by a detailed examination of their respective methods of operation. Finally, we will discusses the current application landscape of HAWTs and VAWTs, highlighting their suitability for different scenarios.

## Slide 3

Key Differences

Axis of Rotation

HAWTs: Characterized by a horizontal axis of rotation, akin to a traditional windmill. The blades rotate parallel to the ground, capturing wind primarily through a lift force mechanism.
VAWTs: Possess a vertical axis of rotation, with blades spinning around a central shaft perpendicular to the ground. These turbines capture wind through a drag force mechanism, regardless of wind direction.


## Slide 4

Wind Direction

VAWTs: Offer a distinct advantage by capturing wind from any direction, eliminating the need for a yaw mechanism. This simplifies their design and reduces maintenance requirements.


HAWTs: Require direct wind direction for optimal operation, necessitating a yaw mechanism to continuously orient the nacelle (housing the generator) towards the prevailing wind.

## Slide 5

Efficiency

- HAWTs : Generally, achieve higher efficiency (up to 50%) compared to VAWTs (35-40%). This is attributed to the consistent wind speed experienced by HAWT blades throughout their rotation cycle.
- VAWTs : Exhibit lower efficiency due to the varying wind speed encountered by their blades during each rotation. However, advancements in VAWT design are continuously improving their efficiency.


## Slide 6

Starting Wind Speed


HAWTs : Require a higher starting wind speed to initiate rotation and electricity generation due to their reliance on lift force.
VAWTs : Can operate at lower wind speeds due to their utilization of drag force, making them suitable for areas with less consistent wind patterns.

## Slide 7

HAWTs : Have a more complex design due to the yaw mechanism and placement of the gearbox at the top of the tower, which necessitates a heavier and more robust tower structure.
VAWTs : Possess a simpler design with the gearbox situated at the base, leading to a potentially lighter tower structure and potentially easier maintenance.

Complexity


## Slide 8


Materials

Both HAWTs and VAWTs primarily utilize the following materials:
- Towers:
- Constructed from steel or concrete for superior strength and stability to withstand wind loads.
- Blades:
- Traditionally manufactured from fiberglass or carbon fiber due to their lightweight and durable properties. Recent developments are exploring the utilization of wood and composites for improved sustainability.
- Shafts and Gears:
- Employ steel due to its exceptional strength to support the turbine and efficiently transmit rotational forces.
- Generators:
- Utilize copper windings and rare-earth magnets to convert the mechanical energy from the shaft into electricity.

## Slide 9

Wind exerts lift force on the blades, causing them to rotate around the horizontal axis.
The rotational motion is transmitted through a gearbox to increase the rotational speed for efficient electricity generation.
The high-speed shaft drives the generator, housed within the nacelle, to produce electricity.
The yaw mechanism continuously adjusts the nacelle orientation to maintain alignment with the prevailing wind direction, maximizing energy capture.

Method of Work HAWTs


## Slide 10

Wind creates a drag force on the blades, regardless of their orientation relative to the wind direction, inducing continuous rotation around the vertical axis.
The varying wind speed across the blades during each rotation cycle impacts their efficiency compared to HAWTs.
In some VAWT designs,

Method of Work VAWTs


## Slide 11

Usage of Each Method

- HAWTs
- Dominate the wind energy industry due to their higher efficiency Ideal for large-scale wind farms in open areas with consistent wind direction.
- VAWTs:
- Gaining traction in recent years due to their, Ability to operate in urban areas with turbulent wind. Lower noise emissions compared to HAWTs, Potential for use in distributed generation applications like rooftops.


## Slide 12

What is Q -blade?
QBlade is an advanced multi-physics software designed to facilitate the comprehensive aero-servo-hydro-elastic development, prototyping, simulation, and certification of wind turbines.
This powerful tool enables highly detailed simulations of wind turbine designs, featuring physics.
models that are more than 30 times faster than real-time. All this functionality is accessible through an intuitive and user-friendly graphical interface.
QBlade is available as standalone software for both Windows and Linux operating systems, with two distinct releases tailored for non-commercial and commercial applications.

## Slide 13

What is Q-Blade used for?

- You can utilize QBlade for various purposes, including:
- Wind Turbine Design (HAWT, VAWT and Multi-Rotor)
- Floater Design and Numerical Testing
- Controller Testing and Optimization
- IEC Design Load Certification
- Wind Farm Simulations and Wake Interaction Studies
- Digital Twins in Python or Matlab Environments


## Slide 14

QBlade can provide several important results for wind turbines, including:

- Power Coefficient:
- QBlade calculates the power coefficient, which is the ratio of the power output of the turbine to the power available in the wind. It indicates the efficiency of the turbine in capturing and converting wind energy. Higher power coefficients indicate more efficient turbines.
- Thrust Coefficient:
- The thrust coefficient, calculated by QBlade, represents the ratio of the thrust force generated by the turbine to the dynamic pressure of the wind. It provides insight into the aerodynamic forces acting on the turbine.


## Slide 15

- Torque and Power Output:
QBlade can calculate the torque produced by the rotor and subsequently estimate the power output of the wind turbine. These results are crucial for assessing the energy production potential of a turbine design.

- Blade Performance:
QBlade can provide detailed information about the aerodynamic performance of the turbine blades, including lift and drag coefficients, angle of attack, and pressure distribution along the blade span. These results are valuable for optimizing blade design and improving overall turbine efficiency.

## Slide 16


Thanks

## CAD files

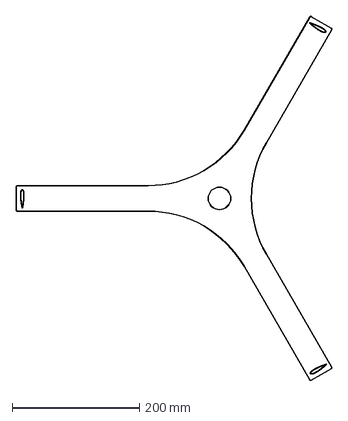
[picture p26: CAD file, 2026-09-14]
DXF/turbine_6mm_wood.DXF
496.9 x 573.1 mm

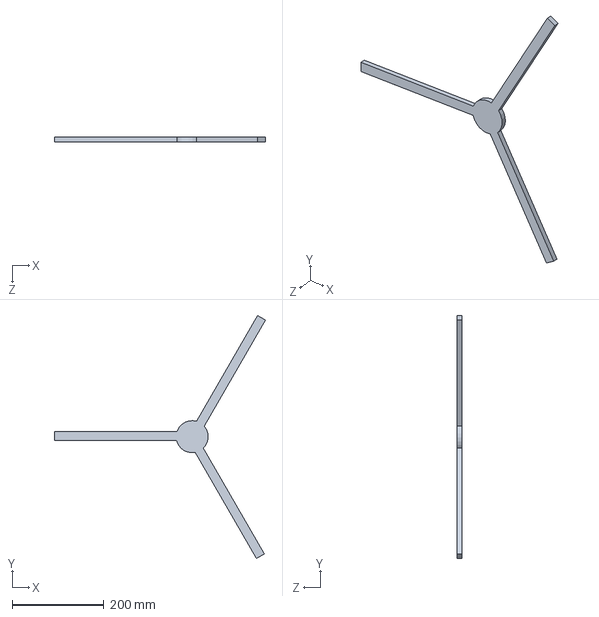
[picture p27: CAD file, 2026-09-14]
Solidworks/HUB.SLDPRT
459.9 x 529.6 x 10.0 mm

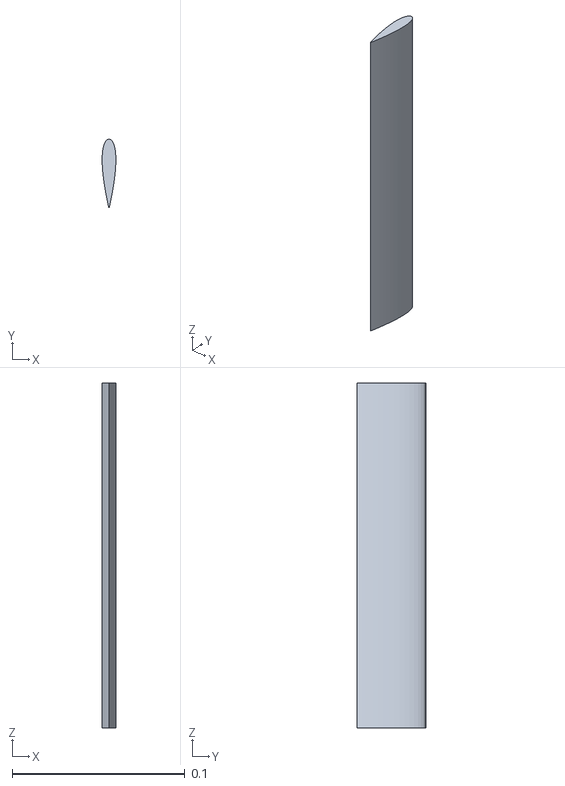
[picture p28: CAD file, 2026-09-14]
VAWT/NACA 0020 VAWT.stl
0.008 x 0.04 x 0.2

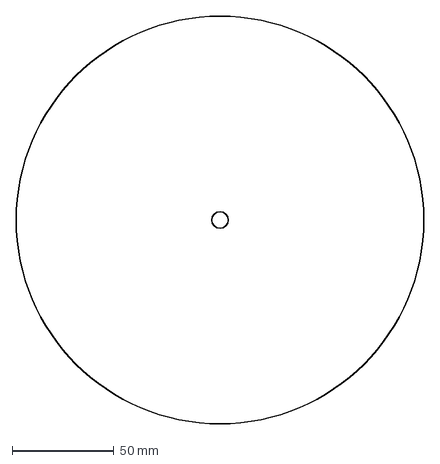
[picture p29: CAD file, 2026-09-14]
DXF/Part1.DXF
200.0 x 200.0 mm

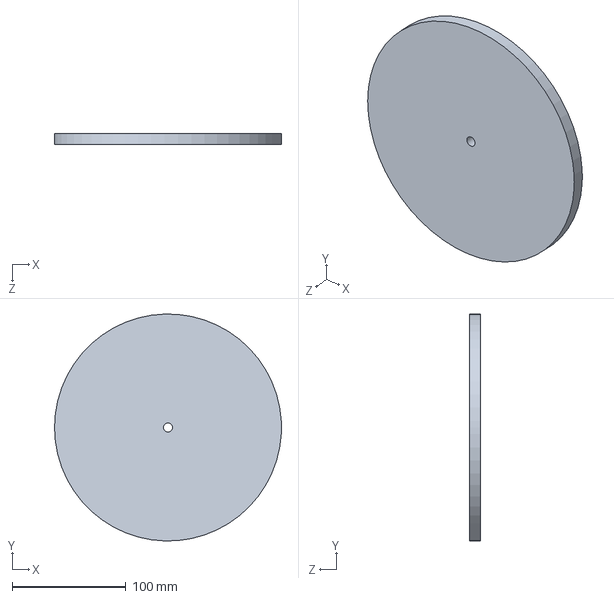
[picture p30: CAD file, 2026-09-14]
Solidworks/cc.SLDPRT
200.0 x 199.9 x 10.0 mm

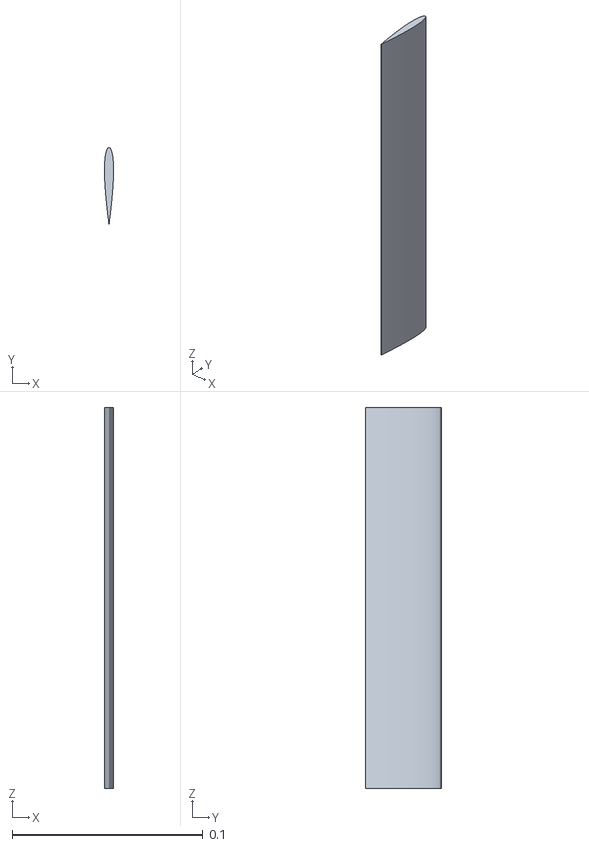
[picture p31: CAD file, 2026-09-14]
VAWT/NACA 0012 VAWT.stl
0.0048 x 0.04 x 0.2

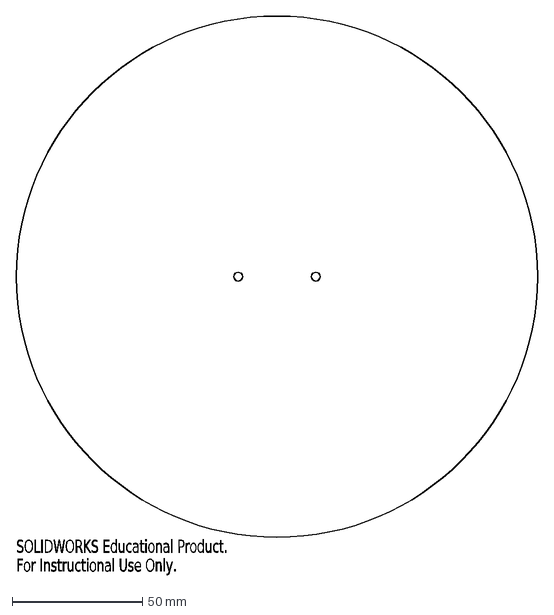
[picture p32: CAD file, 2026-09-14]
DXF/c base.DXF
SOLIDWORKS Educational Product.
For Instructional Use Only.

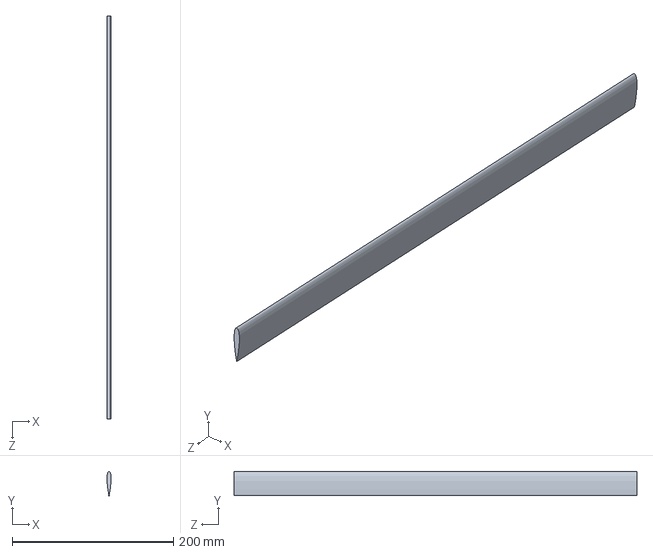
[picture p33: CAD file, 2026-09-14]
Solidworks/Part5.SLDPRT
5.30 x 29.9 x 500.0 mm

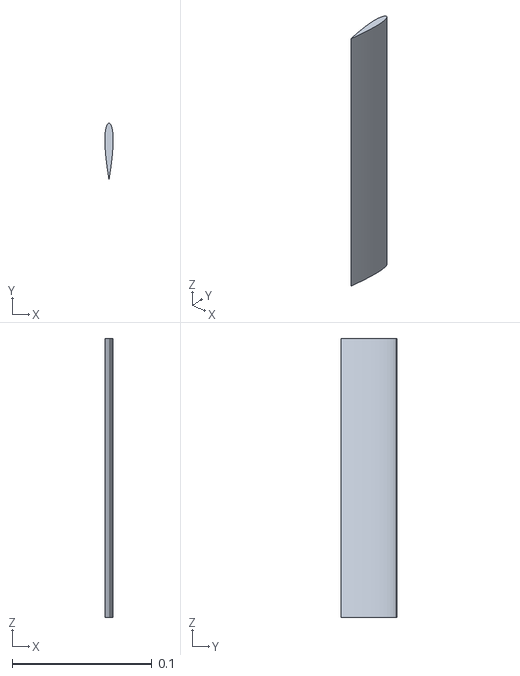
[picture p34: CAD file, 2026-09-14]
VAWT/NACA 0015 VAWT.stl
0.006 x 0.04 x 0.2

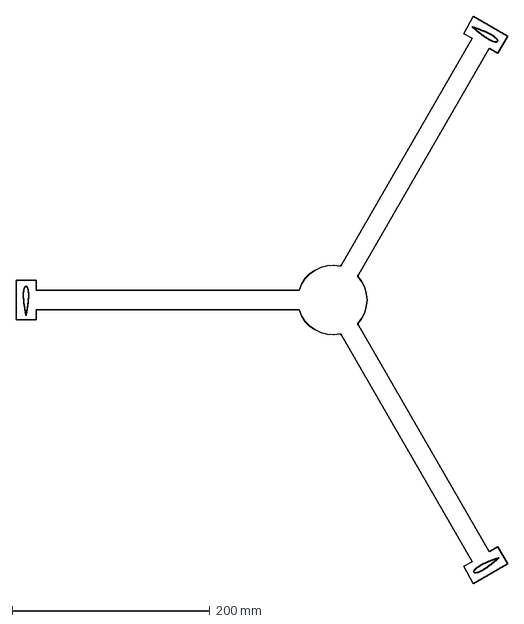
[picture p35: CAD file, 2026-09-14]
DXF/hub new.DXF
497.3 x 574.3 mm

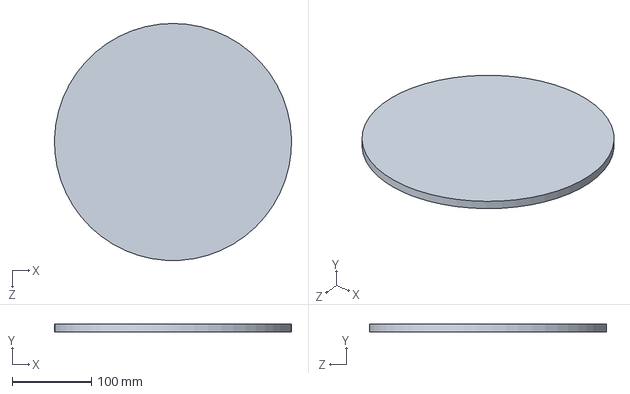
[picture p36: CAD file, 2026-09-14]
Solidworks/ci.SLDPRT
299.9 x 10.0 x 300.0 mm

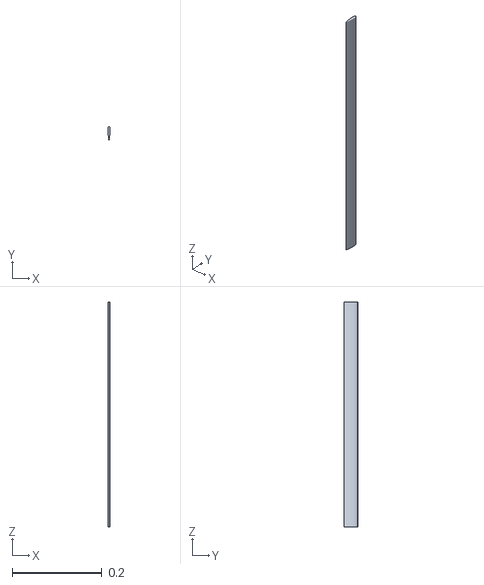
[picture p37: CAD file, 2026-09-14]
VAWT/NACA 0018 VAWT 50cm.stl
0.0054 x 0.03 x 0.5

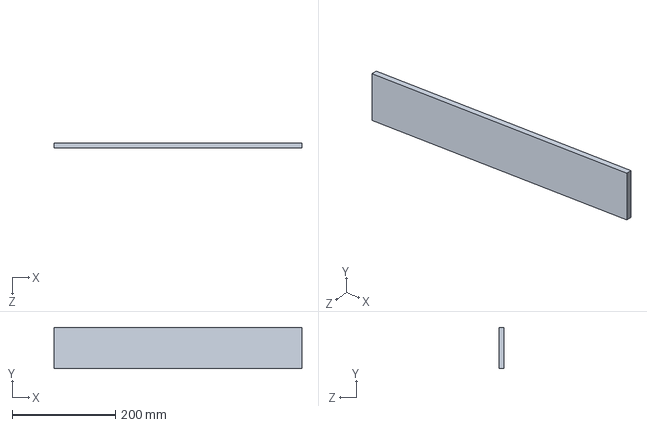
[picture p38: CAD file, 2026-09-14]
Solidworks/hmm.SLDPRT
480.0 x 80.0 x 10.0 mm

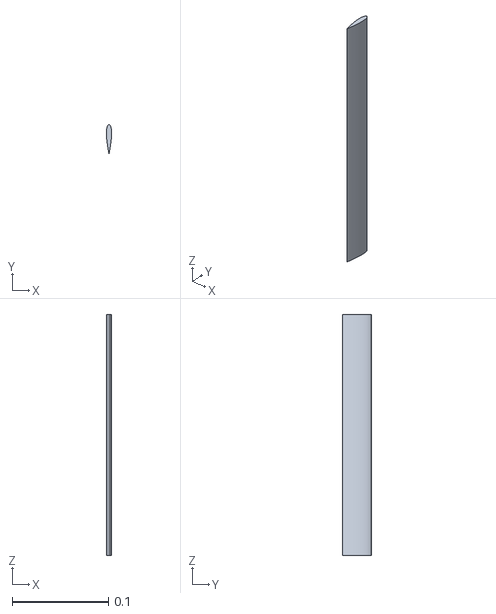
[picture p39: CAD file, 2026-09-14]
VAWT/NACA 0018 VAWT 25cm.stl
0.0054 x 0.03 x 0.25

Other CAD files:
Solidworks/Part3.SLDPRT
VAWT/NACA 0018 VAWT 50cm V1.1.stl
DXF/ci.DXF
DXF/hmm.DXF
